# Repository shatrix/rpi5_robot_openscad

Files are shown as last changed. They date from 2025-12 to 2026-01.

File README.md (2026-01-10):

# Mecha-Style Robot - OpenSCAD Design

> 🔗 **This repository contains the 3D printable designs (OpenSCAD sources, STL, and 3MF files) for the [RPi5 AI Robot Project](https://github.com/shatrix/rpi5-rpios-ai-robot).**

A futuristic, angular robot design featuring a Raspberry Pi 5 head and modular body with mecha/sci-fi aesthetics. All parts are optimized for support-free FDM printing.

## Assembly Overview

```
┌────────────────────────────────────┐
│           ROBOT HEAD               │
│     (robot-head-mecha.scad)        │
│   190 × 125 × 125 mm               │
│                                    │
│   - RPi5 Compartment               │
│   - Display + Camera               │
│   - Speakers + Buttons             │
├────────────────────────────────────┤
│      HEAD BOTTOM INTERFACE         │
│        150 × 100 mm plate          │
│     Connects to → Body Lid         │
├────────────────────────────────────┤
│           BODY LID                 │
│     (top_lid in body file)         │
│   Neck plate: 150 × 100 × 7 mm     │
├────────────────────────────────────┤
│           ROBOT BODY               │
│     (robot-body-mecha.scad)        │
│   150→200 × 151→155 × 50 mm        │
│                                    │
│   - Dual Power Compartments        │
│   - Arm Mounts (both sides)        │
├────────────────────────────────────┤
│      BODY BOTTOM INTERFACE         │
│     (bottom_interface.scad)        │
│   120 mm bolt spacing + cable hole │
│     Connects to → Motors Base      │
└────────────────────────────────────┘
```

---

## Files

| File | Part | Description |
|---|---|---|
| `robot-head-mecha.scad` | **HEAD** | Mecha-style robot head with RPi5 |
| `robot-body-mecha.scad` | **BODY** | Mecha-style robot body with power |
| `bottom_interface.scad` | **INTERFACE** | Cutout pattern for motors base |
| `robot-head-rpi.scad` | HEAD | Original rounded head design |
| `robot-body-rpi.scad` | BODY | Original rounded body design |

---

## Interfaces

### HEAD ↔ BODY Connection

The **head's bottom** connects to the **body's lid** (neck plate).

| Parameter | Value | Notes |
|---|---|---|
| Plate size | 150 × 100 mm | Rounded corners (10mm radius) |
| Plate height | 7 mm | On body lid |
| Slot opening | 100 × 20 mm | Cable passthrough |
| Mounting holes | 4× M3 | At corners (insert holes) |

### BODY ↔ MOTORS BASE Connection

The **body's bottom** uses `bottom_interface.scad` as a **negative cutout** for the motors base STL.

| Parameter | Value | Notes |
|---|---|---|
| Bolt spacing | 120 mm | 4 corners |
| Hole diameter | 4.0 mm | Insert holes |
| Cable hole | 20 mm diameter | Aligned to bottom edge |
| Cutter height | 9 mm | Depth for STL subtraction |

**Usage:** Import `bottom_interface.scad` and subtract from motors base STL.

---

# 🤖 HEAD - robot-head-mecha.scad

The robot head houses the RPi5, display, camera, speakers, and control buttons.

## HEAD - Dimensions

| Parameter | Value |
|---|---|
| Overall Size | 190 × 125 × 125 mm |
| Wall Thickness | 2.0 mm |
| Split Line | z = 48 mm |
| Top Bevel | 18 mm |
| Bottom Bevel | 30 mm |

## HEAD - Components

| Component | Dimensions | Notes |
|---|---|---|
| RPi5 Compartment | 58 × 30 × 89 mm | 60mm rail height |
| Display | 85.5 × 55.6 mm PCB | Wedge rails |
| Camera | 25.4 × 25.4 mm slot | Teardrop cutout |
| Microphone | 9.5 mm diameter | Teardrop cutout |
| Speakers | 40 × 33.6 × 17.8 mm | Both sides, teardrop vents |
| Buttons | 6× 14.5 mm holes | Teardrop shape |
| Magnets | 4× 6.5 × 2.2 mm | At corners |

## HEAD - Support-Free Features

- All holes use teardrop shapes (point up)
- Camera holder has 45° chamfered bottom
- RPi5 rails without top crossbar
- Speaker rails without bottom layer
- Flat top lid for upside-down printing

## HEAD - Printing

| Part | Orientation | Support |
|---|---|---|
| Base | Right-side up (neck on bed) | None |
| Lid | Upside-down (flat top on bed) | None |

---

# 📦 BODY - robot-body-mecha.scad

The robot body holds dual power sources and provides arm mounting points.

## BODY - Dimensions

| Parameter | Value |
|---|---|
| Base Size (bottom) | 150 × 151 mm |
| Top Size | 200 × 155 mm |
| Height | 60 mm |
| Wall Thickness | 1.6 mm |
| Top Bevel | 16 mm |
| Bottom Bevel | 24 mm |

## BODY - Components

| Component | Dimensions | Notes |
|---|---|---|
| Front Chest Vents | 7-6-5 pyramid | Teardrop shape |
| Powerbank (Left) | 37.5 × 80 × 25.5 mm | 13° tilt |
| Battery (Right) | 51 × 86 × 15 mm | 13° tilt |
| Arm Mounts | 48 mm diameter | Both sides |
| Lid Screws | 4× M3 | At corners (replaces magnets) |
| Bottom Bolts | 120 mm spacing | 4 corners |

## BODY - Printing

| Part | Orientation | Support |
|---|---|---|
| Shell | Right-side up (bottom on bed) | None |
| Lid | Neck plate facing up | None |

---

## Customization

### HEAD - Bevel Sizes
```scad
// In robot-head-mecha.scad:
bevel_size = 18;        // Top corners
bevel_size_bottom = 30; // Bottom corners
```

### BODY - Bevel Sizes
```scad
// In robot-body-mecha.scad:
bevel_size = 16;        // Top corners
bevel_size_bottom = 24; // Bottom corners
```

### Render Options (both files)
```scad
show_base = true;
show_lid = true;
show_mockups = true;  // HEAD only
```

---

## Version History

- **v1**: Original rounded designs (`robot-head-rpi.scad`, `robot-body-rpi.scad`)
- **v2**: Mecha-style angular redesign with octagonal beveled hulls
- **v2.1**: Support-free printing optimizations (teardrops, chamfers)

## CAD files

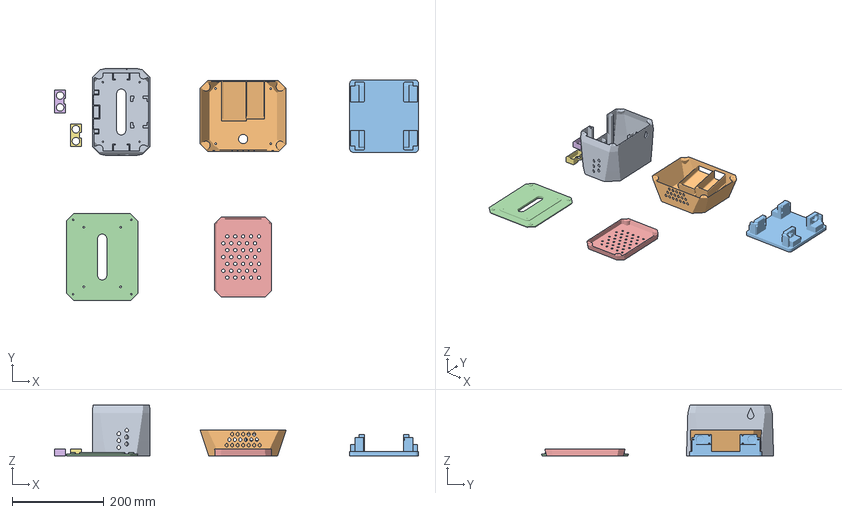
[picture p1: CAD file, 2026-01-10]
full_robot_project.3mf
793.4 x 506.2 x 110.5 mm
rpi_robot_head_base.stl
rpi_robot_body.stl
chassismodule_big.stl
rpi_robot_body_top.stl
rpi_robot_head_lid.stl
sensor_SR04P.stl x 2

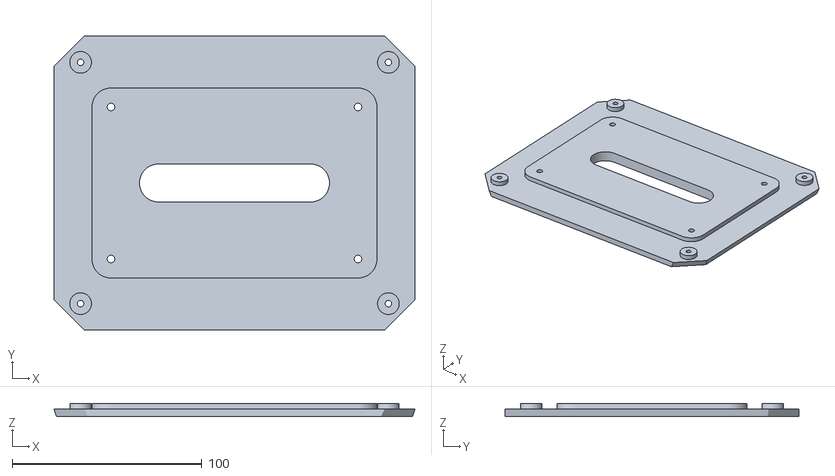
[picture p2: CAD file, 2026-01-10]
stl/rpi_robot_body_top.stl
190.0 x 155.0 x 7.00

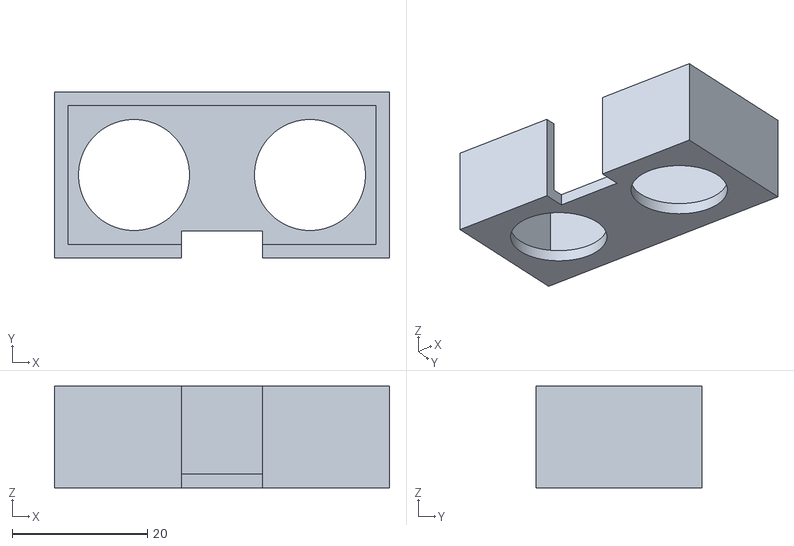
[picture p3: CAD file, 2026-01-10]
stl/sensor_SR04P.stl
49.5 x 24.5 x 15.0

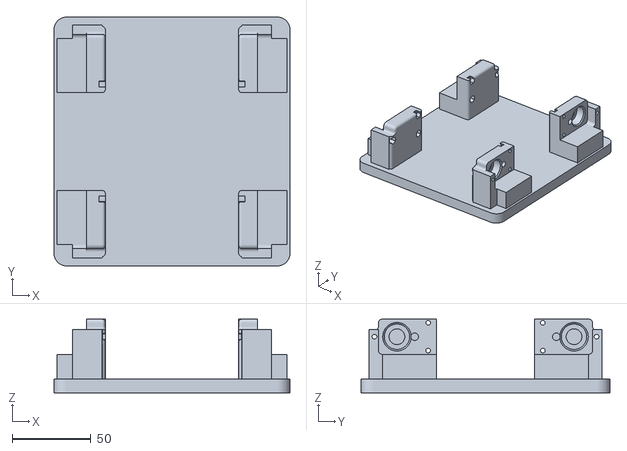
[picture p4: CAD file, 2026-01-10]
stl/chassismodule_big.stl
150.0 x 158.2 x 46.9

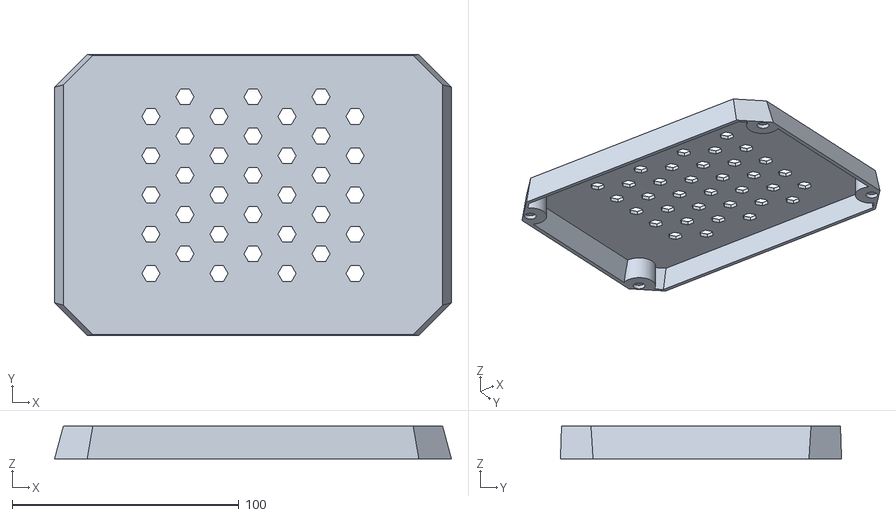
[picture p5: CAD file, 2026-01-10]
stl/rpi_robot_head_lid.stl
175.0 x 123.9 x 14.5

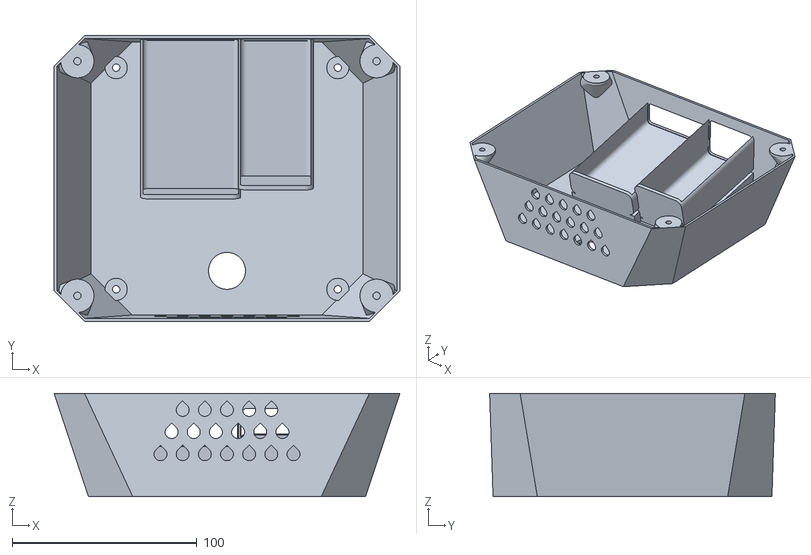
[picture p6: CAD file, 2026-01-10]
stl/rpi_robot_body.stl
187.3 x 154.7 x 56.0

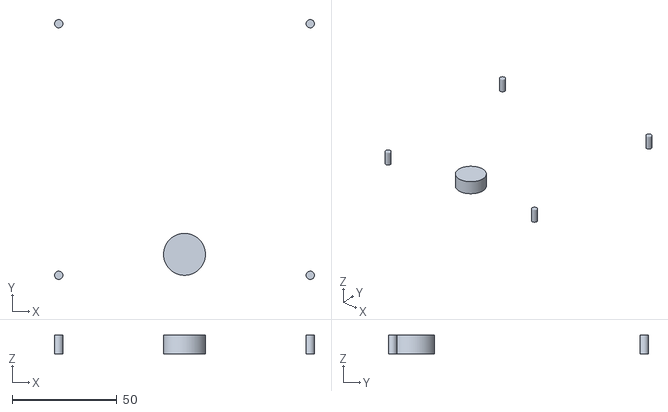
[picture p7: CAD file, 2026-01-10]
stl/interface.stl
124.0 x 124.0 x 9.00

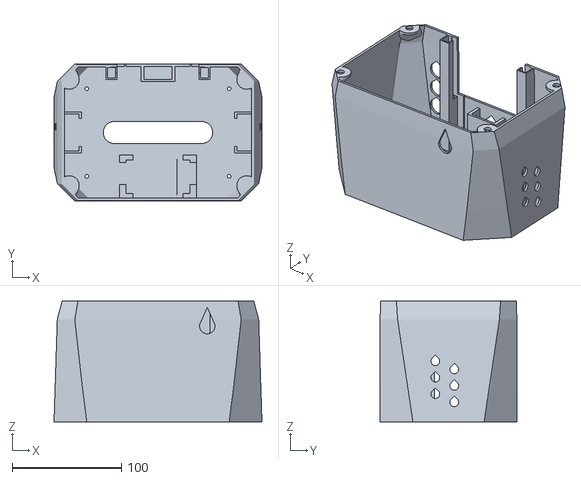
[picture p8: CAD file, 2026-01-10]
stl/rpi_robot_head_base.stl
190.0 x 125.0 x 110.5

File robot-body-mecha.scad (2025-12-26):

// ==========================================
// Project: MECHA-STYLE ROBOT BODY - Angular Sci-Fi Design
// Status: Width 150mm→200mm | Height 50mm | PB + Battery
// Based on: robot-body-rpi.scad
// ==========================================
//
// DESIGN FEATURES:
// - Angular octagonal hull with beveled corners
// - Trapezoid profile preserved (wider at top)
// - Support-free printing optimizations
// ---------------------------------------------------------
// PRESERVED FROM ORIGINAL:
// - Dual power compartments (powerbank + battery)
// - Arm mounts on both sides
// - Neck interface plate
// - Magnet positions at corners
// - Bottom interface bolt pattern
// ---------------------------------------------------------

/* [Render Selection] */
render_part = "ASSEMBLY_VIEW"; // [ASSEMBLY_VIEW, PRINT_BODY_SHELL, PRINT_TOP_LID]

/* [Feature Toggles] */
enable_arm_mounts = true;  // Enable/disable side arm mounts

/* [Printing Tolerances] */
tolerance = 0.2; 

/* [Global Resolution] */
$fn = 80; 

/* [Interface Dimensions] */
bolt_spacing = 20; 
bottom_bolt_spacing = 120; 

screw_hole_dia = 3.4; 
insert_hole_dia = 4.0; 
cable_hole_dia = 16;
bottom_cable_hole_dia = 20; 

/* [Magnet Dimensions] */
magnet_dia = 6.5; 
magnet_thick = 2.2; 

/* [Body Dimensions] */
body_width_base = 150; 
body_depth_base = 151; 
body_width_top = 190; 
body_depth_top = 155;
torso_height = 60;      // Increased from 50mm
wall_thickness = 1.6; 

// Mecha Style Parameters (matching head design)
bevel_size = 16;        // Corner bevel size at TOP
bevel_size_bottom = 24; // Corner bevel size at BOTTOM

/* [Neck Interface Dimensions] */
neck_plate_w = 150;
neck_plate_d = 100;
neck_plate_h = 7; 
neck_plate_radius = 10;
neck_slot_w = 100;
neck_slot_d = 20;

/* [Powerbank Dimensions (Left)] */
ank_w = 37.5; 
ank_d = 80; 
ank_h = 25.5;
ank_corner_rad = 3; 

/* [New Battery Dimensions (Right)] */
batt_w = 51; 
batt_d = 86; 
batt_h = 15; 
batt_corner_rad = 3;

// ==========================================
// CALCULATED VALUES
// ==========================================

lid_thickness = 4; 
split_z = torso_height - lid_thickness; 

// Calculate slopes
wall_slant_angle_x = atan((body_width_top - body_width_base) / 2 / torso_height);
wall_slant_angle_y = atan((body_depth_base - body_depth_top) / 2 / torso_height);

pb_z_center = (torso_height / 2) + 5; 
pb_extra_tilt = 13; 

// --- DUAL COMPARTMENT CENTERING ---
cw = wall_thickness;
compartment_sep = 0.3; 

total_internal_w = ank_w + cw + compartment_sep + batt_w;

pos_pb_x = -(total_internal_w / 2) + (ank_w / 2);
pos_batt_x = -(total_internal_w / 2) + ank_w + cw + compartment_sep + (batt_w / 2);


// ==========================================
// TEARDROP SHAPE (Support-Free Printing)
// ==========================================

// Teardrop 2D profile - point facing UP for no overhangs
module teardrop_2d(d) {
    r = d / 2;
    union() {
        circle(r=r, $fn=32);
        rotate([0, 0, 45])
        square([r, r], center=false);
    }
}

// 3D teardrop hole for horizontal drilling
module teardrop_hole(d, h) {
    linear_extrude(h, center=true)
    teardrop_2d(d);
}

// ==========================================
// MECHA HULL MODULES
// ==========================================

// Angular octagonal profile with beveled corners
module mecha_profile_2d(w, d, bevel) {
    polygon([
        [-w/2 + bevel, -d/2],
        [w/2 - bevel,  -d/2],
        [w/2,          -d/2 + bevel],
        [w/2,           d/2 - bevel],
        [w/2 - bevel,   d/2],
        [-w/2 + bevel,  d/2],
        [-w/2,          d/2 - bevel],
        [-w/2,         -d/2 + bevel]
    ]);
}

// Main mecha outer hull - trapezoid with angular corners
module mecha_hull_outer() {
    hull() {
        // Bottom section (smaller, with bottom bevel)
        translate([0, 0, 0])
        linear_extrude(0.01)
        mecha_profile_2d(body_width_base, body_depth_base, bevel_size_bottom);
        
        // Top section (larger, with top bevel)
        translate([0, 0, torso_height])
        linear_extrude(0.01)
        mecha_profile_2d(body_width_top, body_depth_top, bevel_size);
    }
}

// Inner void matching mecha hull
module mecha_hull_inner() {
    w_base = body_width_base - wall_thickness * 2;
    d_base = body_depth_base - wall_thickness * 2;
    w_top = body_width_top - wall_thickness * 2;
    d_top = body_depth_top - wall_thickness * 2;
    bevel_inner = max(bevel_size - wall_thickness, 2);
    bevel_inner_bottom = max(bevel_size_bottom - wall_thickness, 2);
    
    hull() {
        translate([0, 0, wall_thickness])
        linear_extrude(0.01)
        mecha_profile_2d(w_base, d_base, bevel_inner_bottom);
        
        translate([0, 0, torso_height])
        linear_extrude(0.01)
        mecha_profile_2d(w_top, d_top, bevel_inner);
    }
}

// Front chest vent panel - TEARDROP vents for support-free printing
// Pyramid pattern: 7 bottom, 6 middle, 5 top (matches body trapezoid)
module front_chest_vents() {
    vent_size = 7;
    vent_spacing = 12;
    
    // Position on front face, centered
    y_pos = -body_depth_top/2 - 1;  // Front face (negative Y)
    z_center = torso_height / 2 + 5;
    
    translate([0, y_pos, z_center])
    rotate([90, 0, 0]) {
        // Bottom row: 7 vents
        for (ix = [-3 : 3]) {
            translate([ix * vent_spacing, -vent_spacing, 0])
            teardrop_hole(vent_size, 10);
        }
        // Middle row: 6 vents (offset by half spacing)
        for (ix = [-2.5, -1.5, -0.5, 0.5, 1.5, 2.5]) {
            translate([ix * vent_spacing, 0, 0])
            teardrop_hole(vent_size, 10);
        }
        // Top row: 5 vents
        for (ix = [-2 : 2]) {
            translate([ix * vent_spacing, vent_spacing, 0])
            teardrop_hole(vent_size, 10);
        }
    }
}

// ==========================================
// MAIN RENDER
// ==========================================

if (render_part == "ASSEMBLY_VIEW") {
    color("SlateGray") body_shell_geometry();
    color("DarkSlateGray") translate([0,0,split_z + 30]) top_lid_geometry();
} 
else if (render_part == "PRINT_BODY_SHELL") {
    body_shell_geometry();
} 
else if (render_part == "PRINT_TOP_LID") {
    translate([0,0,-split_z]) top_lid_geometry();
} 

// ==========================================
// GEOMETRY MODULES
// ==========================================

module body_shell_geometry() {
    difference() {
        // Cut at split line for flush top
        intersection() {
            translate([0,0, split_z/2]) cube([1000,1000, split_z], center=true);
            
            union() {
                // 1. Main Mecha Shell
                difference() {
                    mecha_hull_outer();
                    difference() {
                        mecha_hull_inner(); 
                        cube([500,500,4], center=true); 
                    }
                }
                
                // 2. Corner Brackets
                intersection() {
                     corner_mount_brackets();
                     mecha_hull_outer(); 
                }
                
                // 3. Arm Mounts (Auto-tilted) - Optional
                if (enable_arm_mounts) side_arm_mounts_positive();
                
                // 4. Dual Power Casing
                intersection() {
                    dual_power_casing();
                    mecha_hull_outer();
                }

                // 5. Bottom Reinforcement Pads
                intersection() {
                    bottom_reinforcement_pads();
                    mecha_hull_outer();
                }
            }
        }

        // --- DRILLS ---
        union() {
            lid_insert_holes_body();
            bottom_interface_holes(); 
            if (enable_arm_mounts) side_arm_mounts_negative();
            dual_power_cutout();
            front_chest_vents();  // Decorative front vents
        }
    }
}

module top_lid_geometry() {
    difference() {
        union() {
            // Lid Plate (Cap Style) with mecha hull
            intersection() {
                mecha_hull_outer();
                translate([0,0, split_z + lid_thickness/2]) 
                    cube([500,500, lid_thickness], center=true);
            }
            translate([0,0,split_z]) neck_plate_shape();
            
            // Reinforcement pads around screw holes
            lid_screw_reinforcement();
        }
        lid_screw_holes();
        translate([0,0,split_z - 1]) neck_interface_drills();
    }
}

// ==========================================
//          DUAL POWER MODULES (UNCHANGED)
// ==========================================
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

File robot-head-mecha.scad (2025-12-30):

// ########################
// MECHA-STYLE FUTURISTIC ROBOT HEAD - SCI-FI DESIGN
//
// DESIGN FEATURES:
// - Angular faceted geometry with sharp bevels
// - Forward-swept crown for aggressive stance
// - Cheek armor plates with inward taper
// - Hexagonal vent patterns
// - Panel line details
// ---------------------------------------------------------
// PRESERVED FROM ORIGINAL:
// - All internal component dimensions and positions
// - RPi5 compartment with 60mm rail height
// - Screen, Camera, Mic, Button openings unchanged
// - Magnet positions at corners (6.5mm x 2.2mm)
// - Neck interface: 150x100mm plate
// - Split line at z=48mm for lid
// ---------------------------------------------------------

$fn = 80;

/* [Global Settings] */
render_mode = "full"; // [full, test_fit]

show_base = true;
show_lid = false; 
show_mockups = true;
embedded_magnets = false; 

/* [Dimensions] */
head_w = 190; 
head_h = 125; 
head_d = 125; 
wall = 2.0; 
split_z = 48; // Raised split line
corner_r_top = 12; 
corner_r_bot = 30; 

// Mecha Style Parameters
forward_rake = 0;       // Set to 0 for flat top (easier printing)
cheek_taper = 0.12;     // Side taper ratio (0-1)
bevel_size = 18;        // Corner bevel size at TOP (reduced to fit magnets)
bevel_size_bottom = 30; // Corner bevel size at BOTTOM (can be larger)
chin_angle = 20;        // Chin plate angle
crown_height = 0;       // Disabled for flat top printing

/* [Neck Interface Dimensions] */
neck_plate_w = 150;
neck_plate_d = 100;
neck_slot_w = 100;
neck_slot_d = 20;
insert_hole_dia = 3.4; // M3 screw clearance

/* [Hardware Dimensions] */
disp_pcb_w = 85.5; 
disp_pcb_h = 55.6;
disp_pcb_thick = 7.0;

// RPi
rpi_w = 58;           
rpi_thick = 30;       
rpi_h_actual = 89;    
rpi_lift = 0; 

// Dual Speakers
dual_spk_l = 40; 
dual_spk_w = 33.6; 
dual_spk_d = 21;  // Increased from 17.8 to compensate for mecha hull taper 

// Camera Settings
cam_slot_w = 25.4; 
cam_slot_h = 25.4; 
cam_lens_d = 11.4; 
cam_depth = 14; 

// Microphone Settings
mic_d = 9.5; 
mic_holder_wall = 1.0; 

// Push Button Dimensions
pb_main_dia = 14.5; 
pb_nut_dia = 11.3;  
pb_hole_depth = 10.0;

// --- VERTICAL STACK CALCULATIONS ---
floor_z = -head_h/2 + wall;

// Magnet Settings
lip_h = 4; lip_thick = 1.2; lip_inset = 0.8; lip_tol = 0.4;
mag_diam = 6.5; mag_height = 2.2; mag_cover_thick = 0.6;

// --- EXTRA SUPPORT BLOCK ---
enable_support_block = true;
supp_w = 17.5; 
supp_d = 33; 
supp_h = 10.6;
supp_x_offset = ((rpi_w + 12)/2) - (supp_w/2); 

// --- RPi POSITIONING ---
back_inner_wall_global = -head_d/2 + wall;
holder_depth_global = rpi_thick + 10; 
rpi_center_y_global = back_inner_wall_global + holder_depth_global/2;

// --- FRONT FACE STACK ---

// 1. MIC POS (Touching Floor)
mic_holder_radius = (mic_d/2) + mic_holder_wall;
mic_z_pos = floor_z + mic_holder_radius; 

// 2. CAMERA POS (Raised)
mic_top_edge = mic_z_pos + mic_holder_radius;
cam_holder_height = cam_slot_h + 4 + 2; 
cam_holder_half_h = cam_holder_height / 2;
min_gap = 6.0; 
cam_z_pos = mic_top_edge + min_gap + cam_holder_half_h; 

// 3. SCREEN POS
screen_center_z = cam_z_pos + cam_slot_h/2 + 4 + disp_pcb_h/2;



// ==========================================
//          TEARDROP SHAPE (Support-Free Printing)
// ==========================================

// Teardrop 2D profile - point facing UP for no overhangs
// Used for horizontal holes in vertical walls
module teardrop_2d(d) {
    r = d / 2;
    union() {
        circle(r=r, $fn=32);
        // 45-degree triangle pointing up
        rotate([0, 0, 45])
        square([r, r], center=false);
    }
}

// 3D teardrop hole for horizontal drilling
module teardrop_hole(d, h) {
    rotate([0, 0, 0])  // Point facing +Z (up when rotated to front)
    linear_extrude(h, center=true)
    teardrop_2d(d);
}

// ==========================================
//          MECHA HULL MODULES
// ==========================================

// Angular octagonal profile with beveled corners
module mecha_profile_2d(w, d, bevel) {
    polygon([
        [-w/2 + bevel, -d/2],
        [w/2 - bevel,  -d/2],
        [w/2,          -d/2 + bevel],
        [w/2,           d/2 - bevel],
        [w/2 - bevel,   d/2],
        [-w/2 + bevel,  d/2],
        [-w/2,          d/2 - bevel],
        [-w/2,         -d/2 + bevel]
    ]);
}

// Main mecha outer hull with angular geometry and flat top for printing
module mecha_hull_outer(w, d, h, bevel) {
    // Calculate dimensions at different heights
    bottom_w = w;
    bottom_d = d;
    mid_w = w - 4;
    top_w = w - (w * cheek_taper);
    top_d = d - 2;
    
    hull() {
        // Bottom octagon (using bevel_size_bottom for larger angular corners)
        translate([0, 0, -h/2])
        linear_extrude(0.01)
        mecha_profile_2d(bottom_w, bottom_d, bevel_size_bottom);
        
        // Lower mid section (transition from bottom to top bevel)
        translate([0, 0, -h/4])
        linear_extrude(0.01)
        mecha_profile_2d(mid_w, d, (bevel + bevel_size_bottom) / 2);
        
        // Upper mid section (slight inward taper)
        translate([0, 0, h/4])
        linear_extrude(0.01)
        mecha_profile_2d(mid_w - 2, d, bevel - 2);
        
        // Top section - FLAT for printing upside down
        translate([0, 0, h/2])
        linear_extrude(0.01)
        mecha_profile_2d(top_w, top_d, bevel - 5);
    }
}

// Inner void matching mecha hull
module mecha_hull_inner(w, d, h, bevel) {
    wall_t = wall;
    mecha_hull_outer(w - 2*wall_t, d - 2*wall_t, h - 2*wall_t, bevel - wall_t);
}

// Crown ridge on top (DISABLED for flat top printing)
// To enable, set crown_height > 0
module crown_ridge() {
    if (crown_height > 0) {
        ridge_w = head_w * 0.4;
        ridge_d = head_d * 0.6;
        ridge_h = crown_height;
        
        translate([0, 0, head_h/2 - 2]) {
            hull() {
                translate([0, 0, 0])
                linear_extrude(0.01)
                mecha_profile_2d(ridge_w, ridge_d, 8);
                
                translate([0, 2, ridge_h])
                linear_extrude(0.01)
                mecha_profile_2d(ridge_w - 10, ridge_d - 15, 5);
            }
        }
    }
}

// Panel line grooves for tech detail
// Designed for printing without support
module panel_line_grooves() {
    groove_depth = 0.8;
    groove_width = 1.2;
    
    // Vertical accent lines on front - ONLY around camera/mic area
    cam_line_z_min = floor_z;
    cam_line_z_max = cam_z_pos + 20;
    cam_line_height = cam_line_z_max - cam_line_z_min;
    cam_line_center_z = (cam_line_z_min + cam_line_z_max) / 2;
    
    for (x_off = [-30, 30]) {  // Increased from ±20 to ±30mm spacing
        translate([x_off, head_d/2 + 1, cam_line_center_z])
        rotate([90, 0, 0])
        linear_extrude(5)
        square([groove_width, cam_line_height], center=true);
    }
}

// Hexagonal vent pattern for top (centered for flat top)
module hex_vent_pattern_top() {
    hex_size = 8;      // Increased from 6mm to 8mm
    hex_spacing = 10;  // Increased spacing for larger holes
    
    translate([0, 0, head_h/2])
    for (ix = [0 : 6]) {                           // 7 columns
        x = (ix - 3) * hex_spacing * 1.5;          // Centered: -45, -30, -15, 0, 15, 30, 45
        for (iy = [0 : 4]) {                       // 5 rows
            y = (iy - 2) * hex_spacing * 1.73;     // Centered: -34.6, -17.3, 0, 17.3, 34.6
            y_offset = (ix % 2) * (hex_spacing * 0.866);  // Stagger every other column
            translate([x, y + y_offset, 0])
            cylinder(d=hex_size, h=20, $fn=6, center=true);
        }
    }
}

// TEARDROP vent pattern for sides - Support-free printing
module hex_vent_pattern_sides() {
    vent_size = 8;      // Hole diameter
    vent_spacing = 10;  // Spacing between holes
    
    // Z position: shifted down to align with speakers at floor_z
    vent_z_center = -25;
    
    for (side = [-1, 1]) {
        translate([side * (head_w/2), 0, vent_z_center])
        rotate([0, 90, 0])
        for (y = [-12 : vent_spacing * 1.73 : 12]) {
            for (z = [-18 : vent_spacing * 1.5 : 18]) {
                z_offset = (floor((y + 12) / (vent_spacing * 1.73)) % 2) * (vent_spacing * 0.75);
                translate([z + z_offset, y, 0])
                rotate([0, 0, 90])  // Point facing up (+Z in local coords)
                teardrop_hole(vent_size, 20);
            }
        }
    }
}
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

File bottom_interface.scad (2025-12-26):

/* [Interface Dimensions] */
bolt_spacing = 120; 
screw_hole_dia = 3.4; 
insert_hole_dia = 4.0; 
cable_hole_dia = 20; 

/* [Cutter Settings] */
cutter_height = 9; 
selected_dia = insert_hole_dia; 

module interface_pattern() {
    offset_val = bolt_spacing / 2;
    
    // ALIGNMENT CALCULATION
    // The center of the hole is moved up by its radius relative to the bottom screw line.
    // This makes the bottom edge of the circle touch the line connecting the screw centers.
    cable_y_pos = -offset_val + (cable_hole_dia / 2);

    union() {
        // 1. The Cable Hole (Aligned)
        translate([0, cable_y_pos, 0]) 
            cylinder(h = cutter_height, d = cable_hole_dia, center = true, $fn=100);
        
        // 2. The 4 Bolt Holes
        translate([offset_val, offset_val, 0])
            cylinder(h = cutter_height, d = selected_dia, center = true, $fn=50);
            
        translate([-offset_val, offset_val, 0])
            cylinder(h = cutter_height, d = selected_dia, center = true, $fn=50);
            
        translate([-offset_val, -offset_val, 0])
            cylinder(h = cutter_height, d = selected_dia, center = true, $fn=50);
            
        translate([offset_val, -offset_val, 0])
            cylinder(h = cutter_height, d = selected_dia, center = true, $fn=50);
    }
}

interface_pattern();

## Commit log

2025-12-26 Initial commit: Boxy robot head design with RPi5 compartment
    [bottom_interface.scad, robot-body-rpi.scad, robot-head-rpi.scad]
2025-12-26 Add mecha-style robot head design with angular geometry
    Features:
    - Octagonal hull with configurable top/bottom bevels (18mm/28mm)
    - 12% cheek taper for aggressive mecha stance
    - Flat top lid for support-free printing
    - Hexagonal vent patterns on top and sides
    - Panel line grooves on front face
    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
    [robot-head-mecha.scad]
2025-12-26 Add support-free printing optimizations
    Changes:
    - Add teardrop_2d/teardrop_hole modules for support-free holes
    - Convert camera, mic, button holes to teardrop shape
    - Convert speaker side vents to teardrop pattern
    - Chamfer camera holder bottom (45°) for printability
    - Remove RPi5 compartment top bar (was causing overhang tips)
    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
    [robot-head-mecha.scad]
2025-12-26 Add mecha-style robot body and unified documentation
    New Files:
    - robot-body-mecha.scad: Angular mecha-style body design
    - Octagonal hull with configurable bevels (16mm top, 24mm bottom)
    - Trapezoid profile (150mm→200mm width, 50mm height)
    - Dual power compartments (powerbank + battery at 13° tilt)
    - Arm mounts on both sides (48mm diameter)
    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
    [robot-body-mecha.scad]
2025-12-26 Add front chest vents and increase body height
    Body changes:
    - Increase torso_height from 50mm to 60mm
    - Add front_chest_vents module with pyramid teardrop pattern
    - Bottom row: 7 vents
    - Middle row: 6 vents (staggered)
    - Top row: 5 vents
    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
    [robot-body-mecha.scad]
2025-12-26 Replace magnets with M3 screws for body lid
    - Replace magnet holes with M3 screw/insert system
    - Body base: 4.0mm insert holes (8mm depth) for heat-set inserts
    - Lid: 3.4mm screw clearance holes
    - Add lid_screw_reinforcement pads on top of lid (11.4mm × 3mm)
    - Rename modules: corner_mount_brackets, lid_insert_holes_body, lid_screw_holes
    - Update README: Lid Screws (4× M3) replaces Magnets
    More secure than magnets for supporting head weight and motor vibrations.
    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
    [robot-body-mecha.scad]
2025-12-26 Match body top width to head width (190mm)
    - Reduce body_width_top from 200mm to 190mm
    - Now matches robot-head-mecha.scad head_w = 190mm
    - Creates consistent visual alignment between head and body
    [robot-body-mecha.scad]
2025-12-26 Fix battery compartments for support-free printing
    - Replace rounded_box with cube for support columns
    - Add enable_arm_mounts boolean toggle (Feature Toggles section)
    - Support columns now use tapered cubes (no horizontal cylinder overhangs)
    - Battery box shells still use rounded corners for slide-in mechanism
    The rounded_box horizontal cylinders were causing slicer to add tree supports.
    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
    [robot-body-mecha.scad]
2025-12-30 fix(mecha-head): increase speaker compartment depth for taper clearance
    Increased dual_spk_d from 17.8mm to 21mm to compensate for the
    mecha hull's inward cheek taper that was clipping the top of
    the speaker compartments.
    [robot-head-mecha.scad]
2026-01-10 include rendered stl files, 3mf project including all parts for BambuStudio
    [chassismodule_big.stl, full_robot_project.3mf, interface.stl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]
2026-01-10 remove old design scripts
    [robot-body-rpi.scad, robot-head-rpi.scad]
